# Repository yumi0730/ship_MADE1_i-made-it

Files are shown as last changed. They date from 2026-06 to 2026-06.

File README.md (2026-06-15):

# ⛵ MADE1 小船设计项目

基于数学模型的船模设计、稳性分析与制造实践

---

## 📖 项目简介

本项目为宁波工程学院机器人学院工程实践课程项目。

在限定材料、载荷和结构形式的条件下，设计并制造一艘具有良好稳性的单体船模。项目以数学建模为基础，通过 MATLAB 进行参数优化与稳性分析，利用 SolidWorks 和 AutoCAD 完成船体设计，最终采用激光切割工艺制作实体船模并完成水上测试。

项目核心目标包括：

* 满载条件下稳定漂浮
* 甲板保持水平
* 实现约 135° 的稳定消失角（AVS）
* 具有足够的复原力矩
* 尽可能降低航行阻力

---

## 🎯 项目要求

### 材料约束

* 仅允许使用一块 600 mm × 500 mm × 3 mm 椴木板
* 必须采用公式驱动的 CAD 建模方式
* 必须采用单体船设计
* 必须安装桅杆
* 必须承载规定质量的重物

### 性能要求

* 满载后能够正常漂浮
* 满载时甲板与水面平行
* 稳定消失角 AVS ≈ 135°（允许 ±10°误差）
* 最大复原力矩 ≥ 0.2 N·m
* 尽可能提高航行性能

---

## 🔬 设计思路

### 1. 船体数学建模

采用参数化曲面构建船体底部形状：

```math
z=f(x,y)
```

通过调整船体曲面参数：

* A：控制曲率
* B：控制长度
* H：控制高度

利用 MATLAB 对大量参数组合进行遍历分析与筛选。

---

### 2. 稳性分析

针对每组参数计算：

* 船体质量
* 重心（Center of Gravity）
* 浮心（Center of Buoyancy）
* 平吃水线
* 横倾 135° 时浮心位置
* 复原力矩
* 稳定消失角（AVS）

由于船体曲面存在高次项及绝对值项，传统积分计算较为困难，因此采用蒙特卡洛算法估算排水体积及相关参数。

---

### 3. 参数优化

通过程序自动遍历：

```text
A → 曲率参数
B → 长度参数
H → 高度参数
```

依据性能指标筛选最优组合。

最终采用：

```text
A = m
B = 3.8
H = 0.1
```

作为最终设计方案。

---

## 🛠 软件环境

| 软件 | 用途 |
| --- | --- |
| MATLAB | 参数优化与稳性分析 |
| SolidWorks | 三维建模 |
| AutoCAD | 工程图绘制 |
| Mathematical | 曲面可视化 |

---

## 🚢 船体结构

船模主要由以下部分组成：

### 龙骨（Keel）

承担主要支撑结构。

### 肋骨（Ribs）

共设置 5 个主要肋骨截面。

### 甲板（Deck）

采用近似椭圆形设计。

### 桅杆（Mast）

位于船体中心位置。

### 载荷固定结构

用于固定实验规定重物。

---

## ⚙ 制作流程

```text
数学建模
    ↓
MATLAB参数优化
    ↓
SolidWorks三维建模
    ↓
AutoCAD工程图绘制
    ↓
零件排版
    ↓
激光切割
    ↓
船体组装
    ↓
水上测试
```

---

## 📊 理论计算结果

| 参数 | 数值 |
| --- | --- |
| 整船质量 | 1.172 kg |
| 重心位置 | (0,0,0.6407) |
| 135°浮心位置 | (2.226,0,5.619) |
| 平吃水线 | 5.331 |
| 135°吃水线  | 10.122 |
| 复原力矩 | 0.002 |
| 水下阻力截面积  | 0.007 |

---

## 🧪 实验结果

### 成功实现

* 满载稳定漂浮
* 甲板保持水平
* 实际吃水线与理论值接近
* 良好的横向稳定性

### 存在问题

* 实际稳定消失角出现在约 90°
* 与理论设计值 135° 存在偏差
* 后续需要进一步优化重心与浮心配置

---

## 📂 项目目录

```text
MADE1-Boat
│
├── MATLAB
│   ├── Main.m
│   ├── MonteCarlo.m
│   ├── StabilityAnalysis.m
│   └── ParameterSearch.m
│
├── CAD
│   ├── SolidWorks
│   └── AutoCAD
│
├── Images
│   ├── BoatModel.png
│   ├── Assembly.png
│   └── TestPhoto.png
│
├── Report
│   └── 项目报告.pdf
│
└── README.md
```

---

## 📚 涉及知识

本项目综合应用了以下知识：

* 高等数学
* 重积分
* 蒙特卡洛算法
* 工程力学
* 流体静力学
* 船舶稳性理论
* MATLAB 数值计算
* 参数化设计
* CAD/CAM 制造技术

---

## 👨‍💻 项目成员

项目名称：MADE1 小船

组号：42

成员：

* 赖华奇
* 陈雨彤
* 李保同
* 郭嘉霖

---

## 🌟 项目收获

本项目将数学建模、工程力学、计算机辅助设计与实体制造相结合，实现了从理论分析到实体制作的完整工程流程。

通过本项目，团队掌握了：

* MATLAB 数值计算与仿真
* 船体稳性分析方法
* SolidWorks 三维建模
* AutoCAD 工程制图
* 激光切割与结构装配
* 工程项目协作与管理

该项目充分体现了数学、物理与工程技术在实际产品设计中的综合应用价值。

---

## 📄 License

本项目仅用于课程设计、学习交流与学术研究。

版权所有 © Team 42

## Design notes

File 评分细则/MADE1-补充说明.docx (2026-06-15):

1、 小船设计材料清单

名称 | 规格 | 数量 | 备注
木板 | 600*500*3mm | 1
铁质重物 | 圆柱体 | 1 | 重量现场称，需归还
铝质桅杆 | 长500mm，直径10mm | 1 | 重量现场称，需归还
胶带 | | 1 | 需归还
胶水502 | | 1
剪刀 | | 1 | 需归还
美工刀 | | 1 | 需归还
塑料收纳盒 | | 1 | 需归还
塑料薄膜 | | | 3组人员共用一份，用剩的需归还。

2、 文件要求

DXF格式 （可用CAD另存为，选择DXF格式实现）

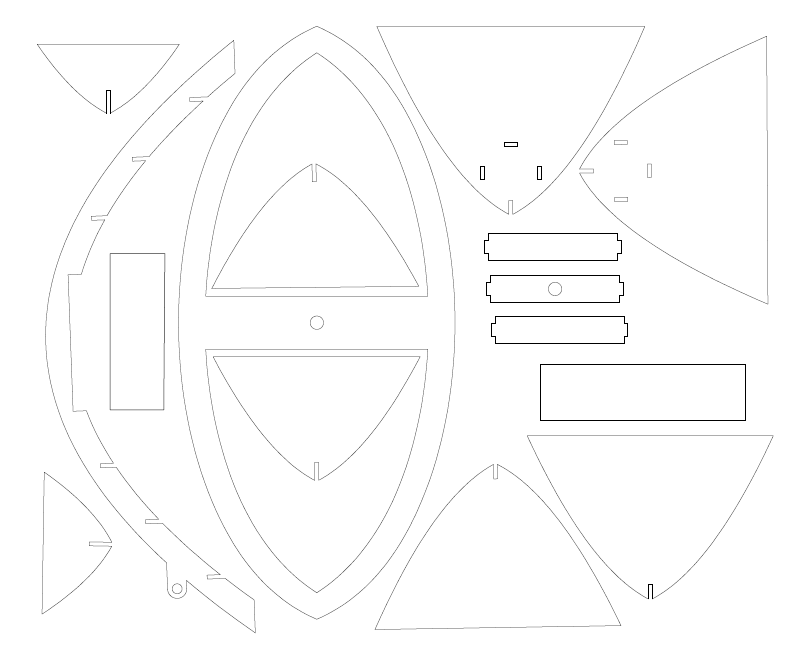
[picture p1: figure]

合理布局，图纸总尺寸不超 600*500mm。

图框务必删除。

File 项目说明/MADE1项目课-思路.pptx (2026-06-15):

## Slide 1

宁波工程学院机器人学院

- 小船设计任务及思路

汪保

## 小船设计要求

1. 当船满载时，必须能够漂浮起来;
2. 当船满载漂浮时，船的甲板应平行于水面;
3. 满载船的稳定消失角（AVS）应该是135度（允许±10度误差）;
4. 船模应具有至少0.2 N-m的最大恢复力矩；
5. 船体设计应尽可能利于在水中快速行进。

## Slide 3

（1）让船浮起来
浮力公式
（a）如何算v排 ？
（b） 如何算质量m ？

## 如何计算v排

二重积分或者三重积分求体积

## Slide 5

如何计算质量

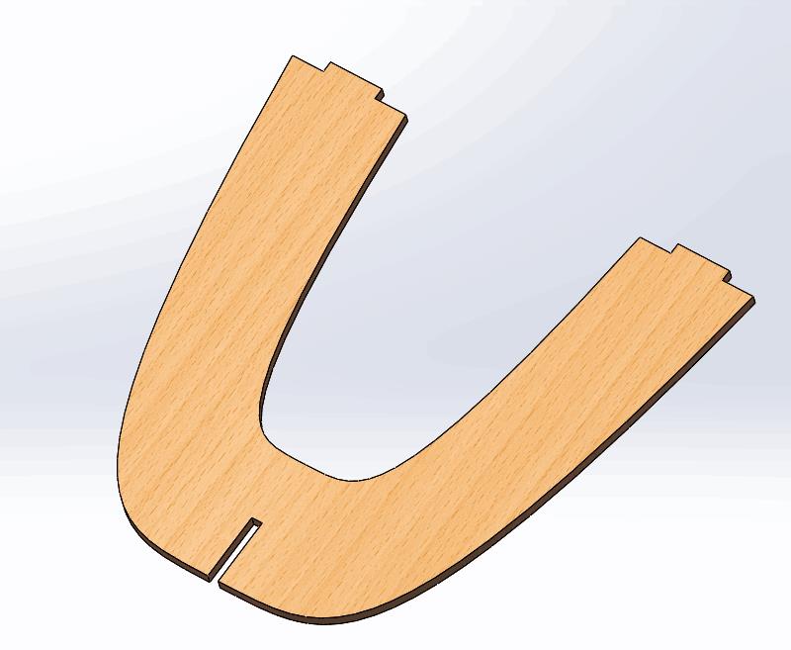
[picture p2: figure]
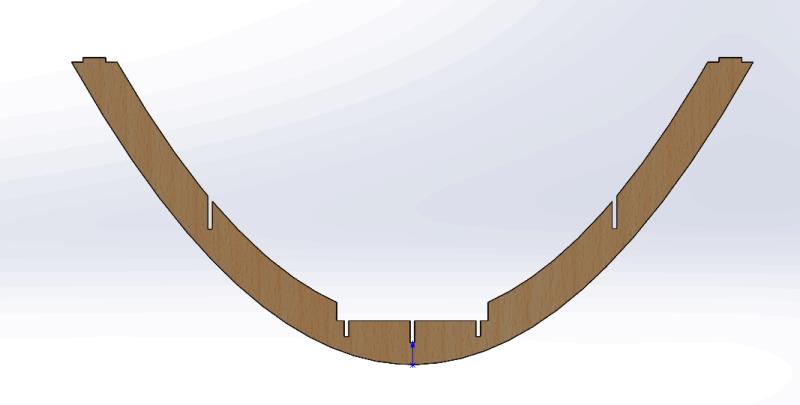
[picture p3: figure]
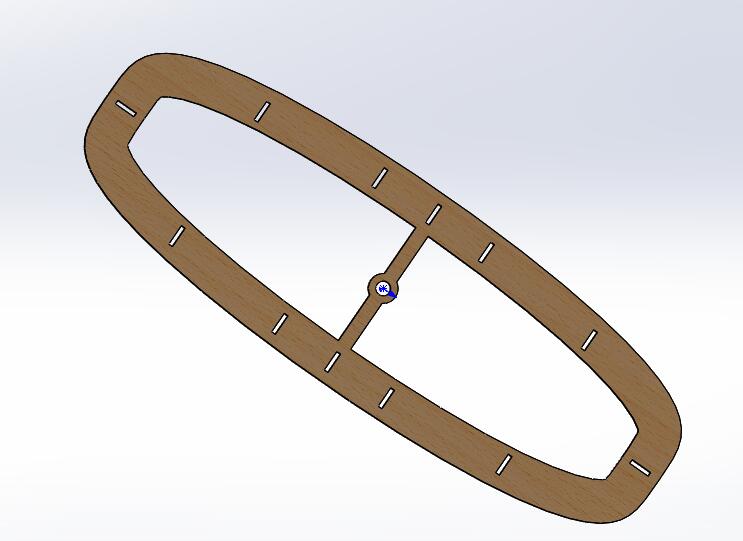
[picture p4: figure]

曲线积分，求长度

## 如何保证稳定消失角是135度

- 计算重心
- 计算浮心

## 复原力矩变化图

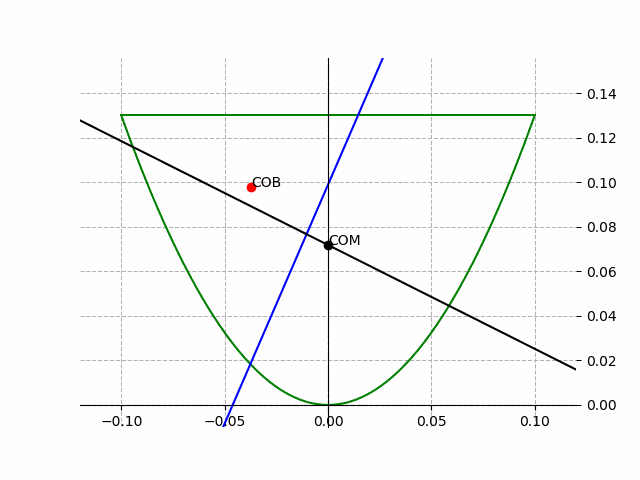
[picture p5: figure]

## 作业

以小船最低点为坐标原点，垂直向上为Z轴，船头至船尾的连线为Y轴建立直角坐标系假设船体底部曲面方程为
船高为 H，桅杆长度0.5m，质量0.1kg，重物的底面半径0.02m，质量1kg，材料面密度为0.1458kg/m²
求
1、龙骨方程
2、任意截面方程
3、甲板方程
4、假设A=1765，B=148，H=0.2

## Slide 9

4.1求吃水线深度
4.2求重心
5.1将小船向x轴倾斜140°求出吃水线所在平面的方程
5.2将小船向x轴倾斜140°，求浮心及复原力矩
6.1画出重物质量与吃水线的曲线图
6.2画出船长、宽、高分别与复原力矩曲线图
6.3 画出重物质量与重心高度坐标的曲线图（曲线图的纵横坐标表示重心高度坐标，曲线上的点的大小表示质量）

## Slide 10

THANKS

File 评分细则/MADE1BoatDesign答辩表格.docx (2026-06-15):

MADE1 Boat Design 最终答辩表格

项目 成员 | 项目展示（15分） | | 质心定位（10分） | | 浮心定位（20分） | | 力矩计算（15分） | | AVS计算（18分） | | 外形（12分） | | 程序（10分） | | | 合计
| PPT与表述（10分） | 英语加分（5分） | 质心位置设计 | 质心定位计算 | 浮心计算原理 | 船身倾斜时浮心计算 | 力矩计算原理 | 复原vs 倾覆 | AVS定义-与力矩的关系 | 力矩（倾角）函数关系 | 材质、受力 | 美观、队名 | 理论理解 | 参与编写 | | 100分
甲
乙
备注

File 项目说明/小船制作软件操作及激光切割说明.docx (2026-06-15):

使用软件：Solidwork2020 cad2020（其他版本都可以）

下载方式：微信搜索软件管家 百度云下载

SolidWorks教程：【半小时快速入门】solidworks3D建模_哔哩哔哩_bilibili (https://www.bilibili.com/video/BV1fV411U7su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)

Soliworks草图画方程曲线：Solidworks里怎么添加方程曲线-百度经验 (baidu.com) (https://jingyan.baidu.com/article/546ae1851b71d51149f28c85.html)

Soliworks零件转工程图：SolidWorks如何将零件图转换为工程图-百度经验 (baidu.com) (https://jingyan.baidu.com/article/fea4511a7bdb21b6ba912514.html)

(仅供参考)

基本步骤(仅供参考)

1. 在SolidWorks草图中绘制你所需的零件形状

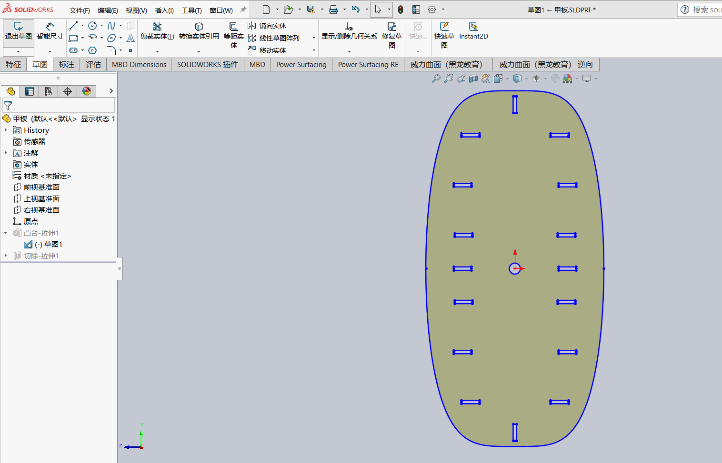
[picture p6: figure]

2. 拉伸凸台3mm形成所需零件

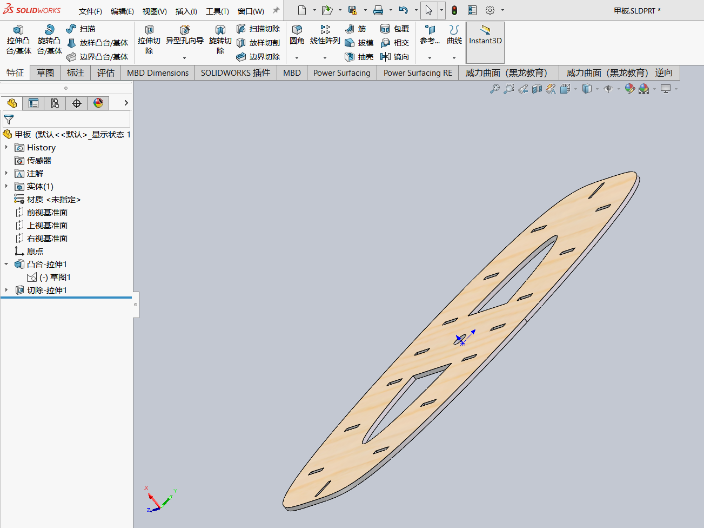
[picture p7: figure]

3. 各个零件之间相互装配 验证制作可行性

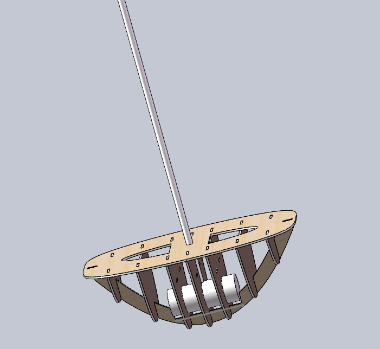
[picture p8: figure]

4. 把每个零件转成工程图保存dwg格式
5. 用cad对所有零件进行排版保存成dxf格式

图纸要求：

1.Cad图纸要求 用cad软件保存成dxf格式

2.所有零件都要排版在500*600mm线框内（如下图所示）

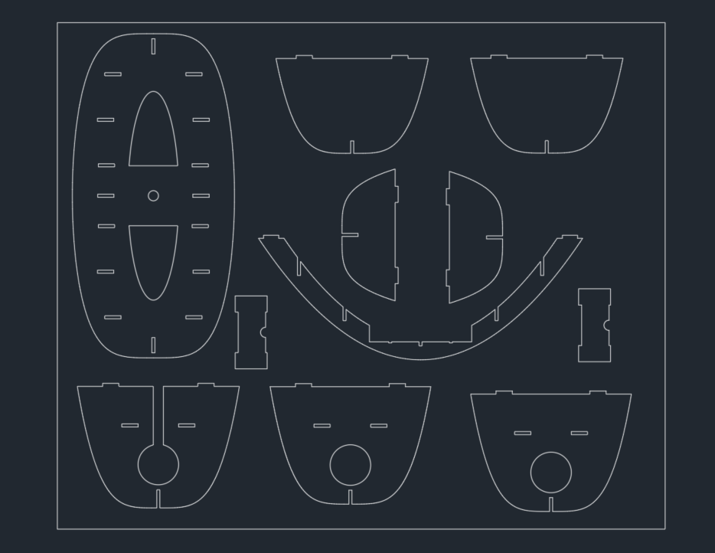
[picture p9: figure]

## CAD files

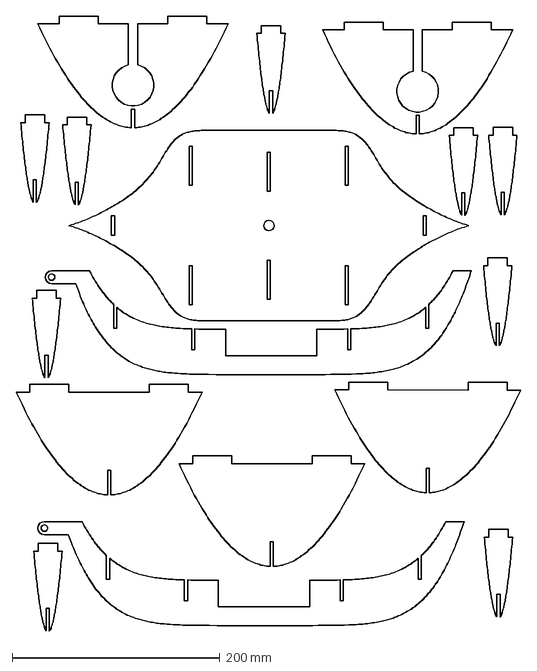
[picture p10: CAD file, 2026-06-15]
龙舟4.0.DXF
485.1 x 591.7 mm
